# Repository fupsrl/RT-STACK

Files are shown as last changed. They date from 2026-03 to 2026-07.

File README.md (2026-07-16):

<p align="center">
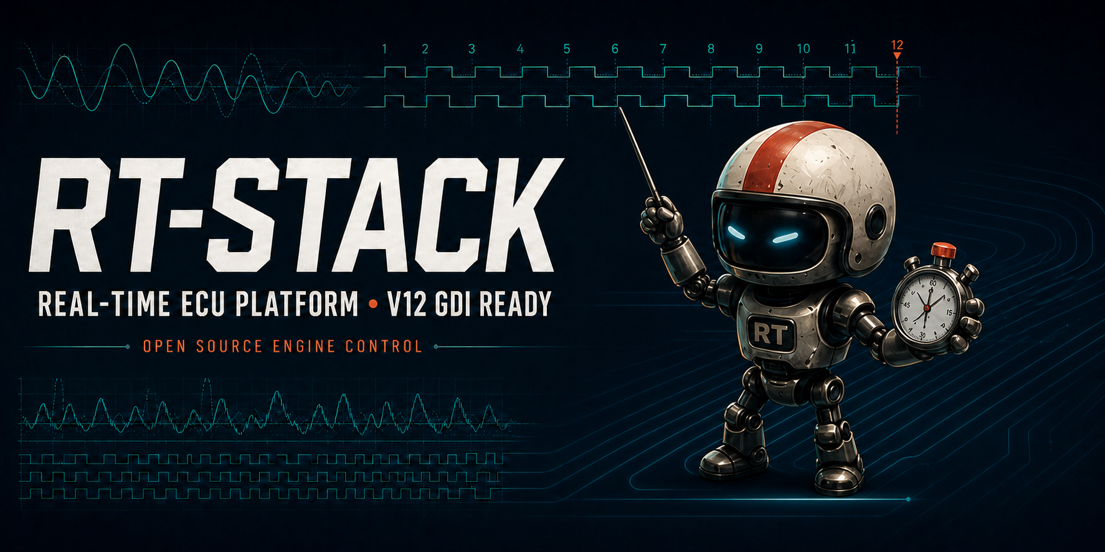
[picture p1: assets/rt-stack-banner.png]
RT-STACK — real-time ECU platform, V12 GDI ready
  
</p>

# RT-STACK

**RT-STACK is an open-source, real-time engine-control platform for experimental, motorsport, and bench-development applications.** It combines a deterministic STM32G4 real-time controller with the option to add a Raspberry Pi or another high-level computer for advanced control, data handling, and calibration workflows.

The hardware is deliberately ambitious—twelve injector channels, twelve ignition channels, trigger inputs, lambda interfaces, CAN, and a standard ECU connector—while the checked-in firmware is a transparent, configurable reference implementation. Start on the bench, understand every signal, then adapt the engine, trigger, and output configuration for your application.

> [!WARNING]
> RT-STACK is an engineering/development project. It is not certified, not road-legal, and is supplied without warranty. Do not connect coils, injectors, fuel pumps, or a running engine until you have independently validated the wiring, trigger decode, outputs, and failsafe behaviour on a safe bench setup.

## Why RT-STACK?

- **Real-time where it matters** — the STM32G474 handles time-critical trigger capture, injection and ignition scheduling.
- **Headroom where it helps** — a companion SBC can run high-level logic, graphical control models, logging, and calibration tooling without putting hard real-time output timing at risk.
- **Engine-agnostic by design** — the platform can be adapted for 2-stroke, 4-stroke, Wankel, Diesel, naturally aspirated, or forced-induction projects.
- **A serious hardware base** — the board is designed for high-channel-count PFI/GDI injection, inductive ignition, trigger sensing, lambda control, and general-purpose outputs.
- **Open calibration path** — the wider FUPSRL toolchain supports CAN/XCP workflows and A2L/HEX artefacts for tools such as ETAS INCA and Vector CANape. The current firmware also includes a 500 kbit/s classic-CAN status message and its DBC.

## Architecture

```text
Crank / cam / sensors
        │
        ▼
STM32G474 real-time layer ──► injector, ignition and I/O drivers
        │                         ▲
        ├── CAN telemetry          │ deterministic time-critical control
        ▼                         │
Optional SBC / high-level layer ──┘
  control logic · logging · calibration · user interface
```

The STM32 is the safety- and timing-critical controller. A companion computer is optional and should be treated as a supervisory layer, not as a replacement for deterministic output control.

## Hardware capabilities

| Area | Capability |
| --- | --- |
| Fuel | 12 injector drivers, intended for general-purpose GDI or PFI use; high-voltage DC/DC injector drive and current sensing |
| Ignition | 12 inductive-spark channels |
| Position sensing | 9 general-purpose trigger interfaces for crank, cam, turbo speed, or other timing inputs |
| Lambda | 2 × CJ125 lambda-controller interfaces |
| Outputs | 12 general-purpose outputs with selectable push/pull behaviour |
| Communications | FDCAN-capable MCU; the checked-in project configures classic CAN at 500 kbit/s and includes two UARTs |
| Processor | STM32G474VETx, with analogue comparators and DAC thresholds for injector-drive control |
| Integration | 186-pin standard ECU connector; designed to stack with a Raspberry Pi breakout board for high-level control |

Selected devices include the STM32G474VETx, ACS722 current sensing, CJ125 lambda interfaces, IR2101/TC4427 gate drivers, RGPR30BM40 ignition IGBTs, and IFX007TAUMA1 push/pull drivers. Consult the KiCad design and BOM before making any electrical decision; this README is an overview, not a wiring specification.

## Firmware: current scope

The firmware project lives in [`SW/RT_STACK_V2`](SW/RT_STACK_V2) and is an STM32CubeIDE / STM32CubeMX project. It provides a clear reference structure rather than a sealed, generic binary:

- **Trigger capture and decoding** — trigger edges are timestamped with the DWT cycle counter. The included decoder is configured for a 60-2 crank wheel, optional cam recognition, and 0–720° phase fusion.
- **Engine configuration** — cylinder count, firing order, ignition/injector channel mapping, dwell limit, boost time, and comparator thresholds are centralised in [`engine_config.h`](SW/RT_STACK_V2/Core/Inc/engine_config.h).
- **Trigger configuration** — crank-wheel and cam-pattern settings are centralised in [`trigger_decoder_config.h`](SW/RT_STACK_V2/Core/Inc/trigger_decoder_config.h).
- **Output scheduling** — [`spark.c`](SW/RT_STACK_V2/Core/Src/spark.c) and [`injection.c`](SW/RT_STACK_V2/Core/Src/injection.c) schedule the configured engine channels.
- **Telemetry** — `RT_Status` is sent as an 8-byte classic-CAN frame at identifier `0x100` every 10 ms; [`RT_STACK_V2.dbc`](SW/RT_STACK_V2/RT_STACK_V2.dbc) describes that message.

The committed engine calibration is an **inline-four example** (firing order `1-3-4-2`) and is not a V12 calibration. V12 readiness describes the available I/O architecture; you must supply a correctly validated configuration for every target engine.

## Quick start — safe development workflow

1. Clone the repository and open [`SW/RT_STACK_V2`](SW/RT_STACK_V2) in STM32CubeIDE. The `.ioc` file retains the CubeMX peripheral configuration.
2. Read `engine_config.h` and `trigger_decoder_config.h` before connecting any engine hardware. Configure only a bench-known target first.
3. Build the **Debug** configuration and flash through a correctly wired ST-LINK connection.
4. With injectors and coils disconnected, verify power rails, CAN traffic, trigger-edge polarity, decoded crank angle, RPM, and cam phase using instruments you trust.
5. Validate each output with suitable loads or test fixtures. Add engine actuation only after the whole chain has been checked.

For a guided explanation of the architecture, firmware configuration, CAN telemetry, calibration direction, and bench validation, read the [RT-STACK documentation](https://fupsrl.com/docs/rt-stack-documentation-v1/).

## Repository layout

| Path | Contents |
| --- | --- |
| [`HW`](HW) | KiCad hardware design files |
| [`FAB`](FAB) | Fabrication/manufacturing material |
| [`SW/RT_STACK_V2`](SW/RT_STACK_V2) | STM32CubeIDE firmware project, DBC, source, and CubeMX configuration |
| [`assets`](assets) | Repository artwork, including this README banner |

## Hardware preview

<p align="center">
  RT-STACK front
  RT-STACK rear
</p>

## Calibration and companion tools

RT-STACK is designed to sit within a broader open tooling workflow. The [CM-STACK Simulink Compiler](https://github.com/fupsrl/CM-STACK-Simulink-Compiler) creates deployable generic-Linux applications and calibration artefacts, while [INCAZ](https://github.com/fupsrl/INCAZ) is a lightweight measurement, calibration, and flash client. Treat each integration as a separately validated engineering step.

## Contributing and support

Issues and pull requests are welcome, especially reproducible trigger-decoder tests, documentation corrections, and validated engine configurations. Please include the RT-STACK revision, firmware commit, engine/trigger setup, power supply conditions, and the measurements or logs that demonstrate the behaviour.

## License

RT-STACK is licensed under [Creative Commons Attribution-NonCommercial 4.0 International](LICENSE.txt). Attribution is required and commercial use is not permitted.

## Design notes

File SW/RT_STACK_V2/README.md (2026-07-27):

# RT_STACK_V2 firmware

This firmware is organized around four intentionally separate concerns:

1. `trigger_capture_stm32.c` timestamps electrical edges.
2. `trigger_decoder.c` interprets user-defined wheel geometry.
3. `engine_control.c` gates the ignition/injection schedulers through a
   fail-safe engine state machine.
4. `dcdc_control.c` regulates VBUS, `dcdc_pwm_stm32.c` owns the
   hardware-synchronous two-phase TIM1 waveform, and
   `dcdc_platform_stm32.c` contains the board/ADC/interrupt integration.

`main.c` is now platform startup and sensor glue. Engine behavior is configured
in tables rather than embedded in the superloop.

## Start here

### 1. Configure the trigger wheels

Edit `Core/Inc/trigger_decoder_config.h`.

- Add one entry to `trigger_wheels[]` for every physical wheel.
- Set its TMG input channel, active edge, mechanical cycle, measured index-zero
  angle, direction, tolerances, filtering, confirmation count, and timeout.
- Choose either a conventional missing-tooth `N-M` wheel or an arbitrary cyclic
  `SHORT`/`LONG` interval pattern.
- Set `wheel_count`, `primary_wheel`, and optional `phase_wheel` in
  `trigger_default_config`.
- Set a measured crank/cam phase-alignment tolerance when a phase wheel is
  enabled.

The default is a crank-only 60-2 wheel on TMG1/PD10. The documented cam example
is deliberately disabled because its actual installed angle must be measured.
Sequential ignition and injection will not run without a configured phase
wheel.

The decoder itself accepts increasing or decreasing angle conventions and
general related wheel cycles. The present ignition/injection scheduler is
intentionally narrower: it enables actuators only for a +1 primary direction,
a 360-degree primary cycle, and a 720-degree engine cycle. Other combinations
remain usable for decoder development but fail actuator compatibility checks.

See [TRIGGER_DECODER.md](TRIGGER_DECODER.md) for pattern conventions, capture
pin capabilities, and integration details.

### 2. Configure the engine and actuators

Edit `Core/Inc/engine_config.h`.

- Set `ENGINE_CYLINDER_COUNT`.
- Give every cylinder an explicit compression TDC, ignition output, and injector
  output. Explicit TDCs support even-fire and odd-fire engines equally.
- Set per-cylinder ignition advance/dwell defaults and accepted limits.
- Set per-cylinder injection start, duration, boost time, and boost/hold DAC
  values.
- Select sequential or intentionally crank-only operation with
  `IGNITION_REQUIRES_PHASE_SYNC` and `INJECTION_REQUIRES_PHASE_SYNC`.

The engine gate derives its phase requirement from the currently enabled
commands. Enabling a sequential command without cam phase moves the controller
to `SYNCING`; disabling all sequential commands permits an intentionally
configured crank-only scheduler without requiring a reboot.

Physical PCB routing is separate in `Core/Inc/board_output_config.h`; it should
change only for a board revision.

Injection is disabled and calibration-locked by default. The fitted ACS722
sensor is bidirectional, so its nominal midscale is not a safe boost limit and
the example raw DAC codes must not be used with a load. Measure zero-current
code, polarity, codes/ampere, and the required boost/hold currents on every
pair; enter the resulting codes, then set
`INJECTION_CURRENT_CALIBRATION_VALID=1` and deliberately enable injection.
The six current comparators default to 10 mV hysteresis through
`BOARD_INJECTOR_COMPARATOR_HYSTERESIS`; validate that value against measured
noise and current ripple as part of the same calibration.

### 3. Deliberately arm outputs

`ENGINE_OUTPUTS_ARM_AT_BOOT` defaults to `0`. This keeps the firmware safe for
decoder and communications development. Setting it to `1` requests output
operation, but does not bypass configuration validation, synchronization, RPM
limits, event deadlines, or the fault latch.

The application can instead call:

```c
engine_control_request_outputs(true);
```

Only a fault-free `ENGINE_MODE_RUNNING` state can energize an output. Clear a
recoverable fault only after revoking output permission:

```c
engine_control_request_outputs(false);
engine_control_clear_faults();
```

### Stationary injector bench API

The periodic injector test is deliberately unavailable in production builds.
It requires both `INJECTION_CURRENT_CALIBRATION_VALID=1` and
`ENGINE_INJECTOR_TEST_API_ENABLED=1` in `Core/Inc/engine_config.h`. Enable it
only after the peak-and-hold current calibration has been measured on the
assembled board.

The API addresses the physical injector output number (`1..12`), not a
cylinder number. The selected output must appear exactly once in
`engine_cylinders[]`, because that cylinder entry supplies its calibrated
boost/hold profile and accepted pulse-width limits.

```c
engine_injector_test_config_t test = {
  .injector_output = 2U, /* physical INJ2 output */
  .period_ms = 100U,
  .pulse_width_us = 5000U
};

engine_injector_test_result_t result =
    engine_control_start_injector_test(&test);

/* Call engine_control_service() normally while the test is armed. */

engine_control_stop_injector_test();
```

`period_ms` is the start-to-start period and `pulse_width_us` is the injector
on-time. The first pulse occurs only after one complete period; late foreground
service skips missed periods and never emits a catch-up burst. Configured
minimum off-time, maximum duty cycle, mapped-cylinder duration limits, and the
normal 100 us hard-off deadline still apply.

The controller accepts the test only while the engine is stationary, normal
outputs are disarmed, no trigger records are pending, the trigger inputs have
been quiet for `ENGINE_INJECTOR_TEST_QUIET_TIME_MS` (also after startup or an
overcapture), and no fault is latched.
Only one injector may be tested at a time. While armed, the controller reports
`ENGINE_MODE_INJECTOR_TEST` and rejects normal output arming. Any trigger edge
immediately switches every injector off, cancels the test, and latches
`INJECTION_FAULT_DEBUG_INTERLOCK`; revoke output permission and clear faults
before attempting another test.

## Two-phase DCDC control

The boost converter uses two independent, active-high low-side phases:

- PC0/TIM1_CH1 drives Q31/L1 through the non-inverting TC4427;
- PE13/TIM1_CH3 drives Q32/L2 through the other TC4427 channel.

TIM1 counts up and down. CH1 runs PWM1 with `CCR1 = on_ticks`; CH3 runs PWM2
with `CCR3 = ARR - on_ticks`. The two pulses have equal duty and their centers
and corresponding steady-state edges are exactly one half-period apart. Phase
overlap above 50% is intentional for an interleaved boost converter; these are
not complementary half-bridge switches and timer deadtime is not applied.

All user calibration is in `Core/Inc/dcdc_config.h`. Before any output can be
enabled, that file requires explicit confirmation of feedback linearity,
hardware current-limit protection, and measured power-stage calibration. Then
enter the measured switching frequency, minimum on/off times, duty envelope,
VBUS target/trip/recovery limits, raw ADC watchdog threshold, soft-start rate,
and PID gains. The target and safety values are deliberately zero in the
repository because safe values cannot be inferred from unspecified inductor,
capacitor, thermal, and load ratings.

Runtime control is explicit:

```c
/* PWM stays off until several fresh, plausible VBUS samples are confirmed. */
dcdc_control_request_enable(true);

/* A higher target follows the configured soft-start ramp. */
dcdc_control_set_target_mv(measured_safe_target_mv);

/* Stop switching. This does not discharge the output capacitors. */
dcdc_control_request_enable(false);

/* After a fault: keep disabled, provide a fresh safe VBUS sample, then clear. */
dcdc_control_clear_faults();
```

The boolean APIs report synchronous request acceptance, not a guarantee that
the converter remains enabled. A watchdog or emergency interrupt can latch a
fault immediately afterward; read `dcdc_control_get_state()` for authoritative
state and fault bits.

The controller accepts at most one update per configured control period and
uses the real, deadline-bounded elapsed time for its soft-start, filtered
derivative-on-measurement, and back-calculation anti-windup calculations. It
never emits catch-up duty bursts. Compare values are
preloaded and written as a pair while update events are suppressed, so a timer
boundary cannot mix one old phase with one new phase. A zero-duty command
clears MOE/CEN/channel enables and returns both pins to GPIO-low; a later
nonzero command starts both timer channels as one hardware operation.

VBUS uses PC3/ADC1_IN9. The feedback network is physically:

```text
VBUS -- R145 25 kOhm --+-- VBUS_ADC / PC3
                       +-- R146 1 kOhm -- GND
                       +-- D53 LED ------ GND
                           anode   cathode
```

Without D53, `VADC = VBUS / 26`. D53 is not in series as a harmless indicator;
it is parallel to R146. Once `VADC` approaches the LED forward voltage, LED
current shunts the lower resistor and the transfer becomes nonlinear:

```text
(VBUS - VADC) / 25k = VADC / 1k + I_LED(VADC)
```

The approximate onset is `VBUS = 26 * Vf`: about 47 V for a 1.8 V red LED,
52 V for 2.0 V, 57 V for 2.2 V, or 78 V for a 3.0 V blue/white LED. D53 has no
specified part number, color, minimum-hot `Vf`, or datasheet, so no onset can be
relied on. As a simple 2.0 V clamp illustration, a real 60/80/100 V bus can be
reported near 52 V while LED current rises to roughly 0.32/1.12/1.92 mA. A real
LED has a sloped I-V curve rather than a hard clamp, but it remains strongly
temperature- and part-dependent. The PID can therefore integrate toward maximum
duty while real VBUS keeps rising, and the ADC analog watchdog is blinded if its
threshold is above the same apparent plateau.

D53 must be removed/DNP and the divider characterized before closed-loop use.
On the next PCB, put the indicator on its own rated resistor chain or buffered
driver. R145 is also a single unspecified 0402: with an approximately 2 V ADC
node it dissipates about 85 mW at 48 V, 135 mW at 60 V, and 243 mW at 80 V,
while sustaining roughly 46/58/78 V. Replace it with a voltage- and
power-derated series resistor chain, and add an independent precision
overvoltage comparator to TIM1 break or the power-stage enable.

There is also no phase-current sensing, cycle-by-cycle current limit, external
DCDC enable, or TIM1 break input on the current board. Firmware adds a raw ADC
analog-watchdog shutdown and a 1 ms off-only foreground deadline check, but
neither can protect against inductor saturation, a short, a failed MCU, or a
blocked interrupt. Hardware current limiting, a break/enable path, input
pull-downs, battery transient protection, and validated component ratings are
required before loaded operation. Stopping PWM leaves roughly millifarads of
VBUS capacitance charged; treat OFF as "not switching," not "safe voltage."

## Trigger capture: input capture versus EXTI

Input capture improves timestamp precision because the timer latches the edge
before interrupt latency. It does not remove the ISR or increase throughput by
itself; DMA would be required for that.

A full input-capture conversion is not possible on this PCB: the default crank
PD10 and PD11 have no direct capture channel, several alternatives consume a
shared 16-bit timer, and TIM1 channels conflict with existing outputs. The
implemented hybrid uses:

- free-running 32-bit TIM2 at the APB1 timer clock as the common timebase;
- TIM2_CH4 hardware capture for PA10/TMG5;
- short EXTI handlers that read `TIM2->CNT` for the remaining TMG pins;
- lock-free per-channel queues merged chronologically in the foreground.

Rising+falling (`TRIGGER_EDGE_BOTH`) is accepted only on PA10/TMG5. An EXTI
pending bit cannot retain two opposite edges or their order, so the platform
rejects BOTH-edge configurations on every EXTI-backed TMG input.

This also resolves the PA10/PD10 EXTI-line-10 collision. Queue overflow or TIM2
overcapture is never hidden: synchronization is invalidated and all actuators
are shut down.

## Ignition and injection behavior

Commands are explicit and validated:

```c
spark_command_t spark = { true, 20.0f, 3000U };
injection_command_t fuel = { true, 360.0f, 8000U };

spark_set_command(1U, &spark);
injection_set_command(1U, &fuel);
```

An active event keeps an immutable copy of its timing. Updating a command only
affects the next engine cycle. Shared peak-and-hold injector pairs have explicit
ownership; ambiguous simultaneous events fail closed instead of depending on
table order.

TIM2 compare channel 1 runs a 100 us safety service. It may end coil dwell,
BOOST, or injection, but it can never start an output. Main-loop stalls,
position loss, invalid numeric commands, excessive angle steps, output-pair
collisions, CPU faults, queue overflow, and capture overrun all lead toward OFF.

The independent hardware watchdog is also enabled after platform initialization.
It is refreshed only after a complete foreground control pass and resets the MCU
after roughly one second if that loop locks up. The timeout uses the imprecise
LSI clock and is deliberately not frozen by a debugger; it complements the
100 us actuator deadline service rather than replacing it.

Important hardware limitation: the current PCB has no independent global
driver-enable/break line. Timer IRQ deadlines protect against foreground stalls,
but no software can force GPIO low while the CPU is halted or physically
failed. The actuator/logic inputs also have no external fail-safe pull-downs,
so they are indeterminate during reset before firmware can configure the GPIOs.
Firmware now drives every IGN/BOOST/SEL/comparator-output and DCDC driver net
low directly from `Reset_Handler`, before clock/RAM/C-runtime initialization,
which shortens that window but cannot eliminate the reset interval itself.
Validate with protected dummy loads before connecting coils, injectors, or the
power stage; a future board must add pull-downs and a hardware
watchdog-controlled global driver enable.

PB8/BOOT0 also has no external pull-down. Firmware programs the option bytes to
ignore BOOT0 and boot from flash, but that code can run only after the application
has already booted once. Production boards must program those option bytes during
manufacturing or add a physical pull-down; firmware alone cannot guarantee the
first cold boot.

## Sensors and CAN

- PB2/ADC2_IN12 now supplies the external VBATT reading and uses a long sampling
  time suitable for a divider.
- ADC1 VREFINT is used to calculate VDDA for MCU temperature compensation.
- CAN frames are nonblocking and defined in `RT_STACK_V2.dbc`:
  - `0x100` backward-compatible angle/temperature/raw-voltage status;
  - `0x101` RPM, engine mode, sync/output flags, epoch, and VDDA;
  - `0x102` engine/trigger/actuator faults and loss counters.

### CAN hardware blocker

The present PCB connects MCU PA11 to TJA1051 `TXD` and PA12 to TJA1051 `RXD`,
but STM32G474 FDCAN1 requires PA11=`RX` and PA12=`TX`. Besides preventing CAN
operation, enabling the peripheral would make the PA12 output contend with the
transceiver `RXD` output. Firmware therefore leaves both pins passive and CAN
disabled by default. Swap the two logic-side nets (or use a corrected board),
then set `BOARD_FDCAN1_TRANSCEIVER_WIRING_FIXED` to `1` in
`Core/Inc/board_config.h`.

## CubeMX ownership and regeneration

`Core` is STM32CubeMX's application-code directory; it is not the CMSIS CPU
core. The ownership boundary inside it is important:

- `main.c`, `stm32g4xx_it.c`, `stm32g4xx_hal_msp.c`, and their matching headers
  are Cube-generated scaffolding. Custom code in them is limited to marked
  `USER CODE` blocks.
- Timer modes, pins, DMA and the HSE/PLL configuration are owned by
  `RT_STACK_V2.ioc`. The generated `SystemClock_Config()` and `MX_TIM1_Init()`
  bodies must not be hand-maintained.
- Files such as `engine_control.c`, `trigger_decoder.c`, `dcdc_control.c`, and
  `dcdc_platform_stm32.c` are user-owned modules and Cube leaves them intact.
- `main.c` contains only short initialization/service calls for those modules.
  The generated SysTick handler contains one off-only DCDC deadline hook. The
  fast ADC1 watchdog vector is implemented entirely in
  `dcdc_platform_stm32.c`, so it cannot be erased by regeneration.

ADC1_2 NVIC enable is deliberately owned by the DCDC platform module rather
than the `.ioc`: it is enabled only when all DCDC hardware/calibration gates
permit output, and its first action is the direct MOE shutdown. Do not also
enable the same vector in CubeMX without first changing the platform to use the
Cube-generated handler/HAL callback, or two vector definitions would conflict.

The checked configuration has been regenerated in an isolated directory with
STM32CubeMX and clean-built with STM32CubeIDE. Custom modules and protected hooks
survive; generated clock and TIM1 code are reproduced from the `.ioc`.

## Verification

Trigger host tests:

```text
gcc -std=c11 -Wall -Wextra -Werror -pedantic -ICore/Inc \
  Tests/trigger_decoder_test.c Core/Src/trigger_decoder.c \
  Core/Src/trigger_recorder.c -lm -o trigger_decoder_test
./trigger_decoder_test
```

Actuator host tests:

```text
gcc -std=c11 -Wall -Wextra -Werror -pedantic -DACTUATOR_HOST_TEST \
  -DINJECTION_CURRENT_CALIBRATION_VALID=1 \
  -DENGINE_INJECTOR_TEST_API_ENABLED=1 \
  -ICore/Inc -ICore/Src -ITests/actuators Tests/actuators/test_actuators.c \
  Core/Src/spark.c Core/Src/injection.c -lm -o test_actuators
./test_actuators
```

The CMake test project runs the trigger decoder, sequential actuators,
crank-only actuators, engine-control integration, and pure DCDC PWM/PID suites
with strict warnings. All suites are hardware-independent. The checked CubeIDE
Debug build also links all STM32 sources using the repository linker script.

Before loaded-engine use, perform hardware-in-the-loop sweeps for every wheel
pattern and RPM range, sensor disconnects, noisy/extra/missing edges, stopped
engine at every active-output phase, queue/overcapture injection, and measured
maximum coil/BOOST/injector pulse widths.

## Clock source

The confirmed 20 MHz HSE crystal is the PLL source: `20 MHz / 2 * 34 / 2 =
170 MHz`. Voltage scaling remains range-1 boost, flash latency remains four wait
states, and AHB/APB1/APB2 remain undivided, so TIM1 still receives 170 MHz.
Clock security is enabled after `SystemClock_Config()`. Loss of HSE enters NMI,
forces ignition, injection and DCDC outputs off, then resets the MCU. If USB or
another exact-48-MHz peripheral is added later, use HSI48/CRS rather than trying
to derive 48 MHz from the 340 MHz PLL VCO.

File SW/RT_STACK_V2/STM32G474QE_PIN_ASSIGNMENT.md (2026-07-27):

# STM32G474QE pin assignment for the RT-STACK redesign

Status: proposed LQFP128 board contract, checked against the STM32CubeMX 6.17 device database for `STM32G474Q(B-C-E)Tx`. It intentionally does not change the current STM32G474VET6 `.ioc`; the present firmware still targets the old LQFP100 board.

The machine-readable, package-pin-by-package-pin assignment is in [STM32G474QE_PIN_ASSIGNMENT.csv](STM32G474QE_PIN_ASSIGNMENT.csv). The 24 serialized outputs have their own contract in [STM32G474QE_SERIAL_OUTPUT_ASSIGNMENT.csv](STM32G474QE_SERIAL_OUTPUT_ASSIGNMENT.csv).

## Design assumptions

This assignment keeps all functions found in the current firmware and the draft `mcu.kicad_sch`:

- nine crank/cam/spare timing inputs;
- 12 ignition commands;
- six injector-pair select, BOOST, current-sense and comparator paths;
- 12 conditioned 12 V inputs and 12 protected 12 V outputs;
- two interleaved DCDC PWM outputs, VBUS feedback and a hardware-limit input;
- two CJ125 wideband-lambda interfaces with independent ADC and heater-control paths;
- three FDCAN buses, four serial links and two dedicated SPI buses;
- a 24-bit serialized low-speed control bank, including nine programmable trigger pull-ups;
- two status LEDs, HSE, SWD, reset and boot control.

It also preserves the existing external injector current-limit gates, so `COMP1_OUT` through `COMP6_OUT` still consume physical pins. Removing those six pads is possible only if the external gating circuit is redesigned around internal timer/HRTIM break paths.

## Serialized low-speed control and programmable pull-ups

The timing sheet already contains U62, an 8-bit `SN74LV8T595`-style part, although its outputs are currently unconnected. Nine trigger pull-ups alone exceed that capacity. Reuse U62 as the first stage and make the new chain **24 bits: U62 plus two additional 8-bit stages**. A single additional stage would provide only 16 bits and is too tight once safe output-enable, direct CJ125 chip selects, CJ125 reset and preservation of PA0/USB/BOOT0 are included.

SPI1 is dedicated to this output chain:

| Signal | MCU pin | Function |
|---|---:|---|
| `SERIAL_CTRL_SCK` | PG2 / pin 84 | SPI1_SCK, AF5 |
| `SERIAL_CTRL_MOSI` | PG4 / pin 86 | SPI1_MOSI, AF5 |
| `SERIAL_CTRL_LATCH` | PG5 / pin 103 | Storage-register clock |
| `SERIAL_CTRL_OE_N` | PF2 / pin 26 | Asynchronous bank disable, external pull-up |

Cascade each stage's serial output into the next stage and latch all 24 bits atomically:

| Bit | Logical output | Reset-safe value |
|---:|---|---:|
| 0 | `CRANK_PULLUP_EN` | 0 |
| 1 | `CAM1_PULLUP_EN` | 0 |
| 2 | `CAM2_PULLUP_EN` | 0 |
| 3 | `CAM3_PULLUP_EN` | 0 |
| 4 | `CAM4_PULLUP_EN` | 0 |
| 5 | `SPARE1_PULLUP_EN` | 0 |
| 6 | `SPARE2_PULLUP_EN` | 0 |
| 7 | `SPARE3_PULLUP_EN` | 0 |
| 8 | `SPARE4_PULLUP_EN` | 0 |
| 9 | `GPIO12V_OUT1` | 0 |
| 10 | `GPIO12V_OUT2` | 0 |
| 11 | `GPIO12V_OUT3` | 0 |
| 12 | `GPIO12V_OUT4` | 0 |
| 13 | `GPIO12V_OUT8` | 0 |
| 14 | `GPIO12V_OUT9` | 0 |
| 15 | `GPIO12V_OUT11` | 0 |
| 16 | `GPIO12V_OUT12` | 0 |
| 17 | `LED2` | 0 |
| 18 | `CJ125_RESET_RELEASE` | 0 |
| 19–23 | Reserved | 0 |

Only slow, non-timing protected outputs move to this bank. `IGNx`, injector select, BOOST, DCDC and both lambda-heater PWM signals remain direct MCU outputs. The serialized `GPIO12V_OUT` channels are not suitable for edge-scheduled injection/ignition or independent high-rate PWM.

The pull-up bits must control a high-side switch or analog switch that inserts each raw input's +5 V pull-up resistor. Do not connect a shift-register output directly to a trigger signal: driving a logic zero would clamp the sensor input rather than disconnect its pull-up. Keep the comparator-output-side +3.3 V pull-ups fixed so every MCU capture input always has a defined logic level.

`/OE` must not remain tied low as it is in the current draft. Give PF2 an external pull-up and arrange `/SRCLR` and the external load controls so reset means disabled. Firmware must hold PF2 high, shift the complete all-zero safe image, pulse `SERIAL_CTRL_LATCH`, and only then drive PF2 low. External pull-downs must keep every load off while the register outputs are high impedance; the level-shifted CJ125 reset must remain asserted. A watchdog or MCU reset must immediately return `/OE` high.

Maintain one 24-bit shadow word and update it under one owner. Every transaction transmits all 24 bits before one latch pulse, so unrelated outputs cannot glitch. Treat trigger electrical-mode changes as stopped-engine configuration: disable capture processing, update and latch the pull-up mask, clear pending/overcapture state, then reacquire synchronization.

Expose this as a named per-channel setting such as `trigger[i].pullup = DISABLED | ENABLED`; never expose serialized bit numbers to the user. Validate the requested electrical mode alongside polarity, capture edge and digital-filter settings before accepting a wheel configuration.

## The nine trigger inputs

The correct peripheral mode is **timer input capture**, not input compare. The G474 has only two 32-bit general-purpose timers, TIM2 and TIM5, with four capture channels each. Therefore eight 32-bit captures is the physical maximum; a ninth independent 32-bit capture does not exist on this MCU.

| Logical input | Package pin | Port | Capture channel | AF | Counter |
|---|---:|---|---|---:|---:|
| CRANK_TRG | 113 | PD3 | TIM2_CH1 | 2 | 32 bit |
| CAM1_TRG | 114 | PD4 | TIM2_CH2 | 2 | 32 bit |
| CAM2_TRG | 117 | PD7 | TIM2_CH3 | 2 | 32 bit |
| CAM3_TRG | 116 | PD6 | TIM2_CH4 | 2 | 32 bit |
| CAM4_TRG | 97 | PF6 | TIM5_CH1 | 6 | 32 bit |
| SPARE1_TRG | 15 | PF7 | TIM5_CH2 | 6 | 32 bit |
| SPARE2_TRG | 16 | PF8 | TIM5_CH3 | 6 | 32 bit |
| SPARE3_TRG | 17 | PF9 | TIM5_CH4 | 6 | 32 bit |
| SPARE4_TRG | 1 | PE2 | TIM3_CH1 | 2 | 16 bit + software epoch |

This mapping deliberately spends the two QUADSPI pin banks and some FMC alternatives. It avoids PA0–PA3, the fast ADC5 pins and almost all HRTIM pins. That is the right trade unless external parallel/QSPI memory is a firm requirement.

At a suggested 10 MHz common timer tick, TIM2/TIM5 wrap after about 429.5 s and TIM3 wraps every 6.5536 ms. Maintain a TIM3 overflow epoch and form a wider timestamp before passing an event to the decoder. The clock rate, filter and polarity belong in per-channel configuration; do not bake them into the ISR.

TIM2, TIM5 and TIM3 must share a timestamp domain. Configure the same timer-kernel clock and prescaler, synchronize their initial reset/start through the timer master/slave ITR network where the final CubeMX configuration permits it, and verify the measured counter offsets at startup. Do not compare raw CCR values from independently started counters.

### Is capture actually better than EXTI plus an ISR?

Yes. The current EXTI path timestamps an edge only after interrupt entry by reading `TIM2->CNT`, so interrupt latency and pre-emption become timestamp error. Input capture latches the counter in `CCR1..CCR4` at the hardware edge. ISR latency then affects only how quickly the sample is drained, not its time.

It also gives:

- per-channel edge polarity and digital filtering;
- an overcapture flag when software fails to drain a previous edge;
- DMA as an option for the highest-rate channels;
- a clean ISR that copies `{CCR, edge, status}` into a queue while decoding remains outside interrupt context.

The limitation is that each channel still has one CCR latch. A second edge before the first is consumed causes overcapture, so use DMA or a sufficiently short interrupt path for the crank input.

## Timed outputs

The remaining timer-rich pins are assigned to functions that benefit from deterministic edges:

| Function group | Pins/peripheral | Result |
|---|---|---|
| IGN1–4 | PF12–PF15 / TIM20_CH1–4 | Four hardware output-compare channels |
| IGN5–8 | PE9, PE11, PE13, PE14 / TIM1_CH1–4 | Four hardware output-compare channels |
| IGN9–10 | PE3, PE4 / TIM3_CH2–3 | Shares the 10 MHz time base with SPARE4 capture |
| IGN11 | PB15 / HRTIM1_CHD2 | HRTIM set/reset output |
| IGN12 | PA6 / TIM16_CH1 | Hardware output-compare channel |
| BOOST12–BOOST1112 | PA8, PA9, PA10, PB12, PB13, PB14 / HRTIM A1, A2, B1, C1, C2, D1 | Six independently controlled high-resolution outputs |
| DCDC phases | PC8, PC9 / HRTIM E1, E2 | One HRTIM timing unit, two interleaved outputs |
| Lambda heater 1 | PF10 / TIM15_CH2 | Independent hardware PWM, AF3 |
| Lambda heater 2 | PB7 / TIM4_CH2 | Independent hardware PWM, AF2 |

Every actuator command is active high. Add a physical pull-down at each gate/driver input and initialize timer output state and GPIO output-data registers before switching a pad to output or alternate-function mode.

The mixed timer instances should be hidden behind a table-driven channel descriptor. User-facing configuration should identify `IGN1`, `BOOST34`, and so on; it should never require the user to know that one channel is on TIM20 and another is on HRTIM D.

## DCDC implementation

Use PC8/HRTIM1_CHE1 and PC9/HRTIM1_CHE2. For period `T` and duty `D`:

- phase A set event: `0`; reset event: `D*T`;
- phase B set event: `T/2`; reset event: `(T/2 + D*T) mod T`.

Write all compare values through HRTIM preload registers and transfer them on the same period event. Trigger the VBUS ADC conversion from HRTIM at a repeatable quiet point in the switching cycle, feed that sample to the PID, clamp the requested duty and rate-limit it before the next preload transfer.

PD14/COMP7_INP is reserved for an independent DCDC overcurrent/overvoltage signal. Route COMP7 internally to HRTIM external event 5 or 10 for a cycle-by-cycle output reset. Use PB11/HRTIM1_FLT4 for the separately latched gate-driver or analog fault that requires an explicit clear. PB10 is a resistor-selectable second external fault option on HRTIM1_FLT3.

The DCDC must start disabled and stay disabled until clocks, ADC calibration, VBUS plausibility and fault inputs are valid. PID software is not a substitute for cycle-by-cycle hardware shutdown.

## Dual CJ125 lambda interfaces

Both CJ125s share SPI4 but retain direct, separately pulled-up chip selects:

| CJ125 signal | Channel 1 | Channel 2 | Notes |
|---|---|---|---|
| SPI clock | PE12 / SPI4_SCK | Shared | AF5 |
| SPI data to CJ125 | PE6 / SPI4_MOSI | Shared | AF5 |
| SPI data from CJ125 | PE5 / SPI4_MISO | Shared | AF5; only the selected device may drive it |
| `/SS` | PG0 | PG1 | Direct GPIO; high/inactive through reset |
| `UA` | PC0 / ADC1_IN6 | PA4 / ADC2_IN17 | Lambda/pump-current signal |
| `UR` | PE8 / ADC3_IN6 | PE10 / ADC4_IN14 | Ri/temperature signal |
| Heater PWM | PF10 / TIM15_CH2 | PB7 / TIM4_CH2 | Direct hardware PWM; never serialized |
| `/RST` | `SERIAL_Q18` | Shared | Active low through a proper 5 V-domain reset/level-shift stage |

ADC1/ADC2 can sample the two `UA` channels simultaneously, while ADC3/ADC4 can do the same for both `UR` channels. This keeps PA0 available for future fast analog work. Bosch specifies 16-bit SPI frames at up to 2 Mbaud. Keep the CJ125 bus on SPI4 and the output registers on SPI1; this avoids changing SPI mode or disturbing the serialized control image during lambda traffic.

CJ125 is a 5 V device. Use explicit unidirectional 3.3 V-to-5 V translation for SCK, MOSI, both `/SS` signals and reset, and a 5 V-to-3.3 V path for MISO. Pull both `/SS` inputs high on the CJ125 side. Do not assume that a nominally 5 V-tolerant STM32 input solves the output-high threshold in the opposite direction.

The existing `uego.kicad_sch` divides each `UA` and `UR` output with 600 ohm over 1 kohm. Its 0.625 ratio is appropriate for mapping approximately 5 V into the 3.3 V ADC range, but its roughly 1.6 kohm total resistance loads the CJ125 output by milliamps. Bosch specifies the `UA` output swing under a load below 10 microamps. Replace that network with a high-impedance divider followed by an ADC buffer, or buffer first and then attenuate; retain anti-alias filtering and ADC clamp protection. Route the scaled signals listed above, never raw 5 V-domain `UA`/`UR`.

Each heater needs a protected low-side power stage, hard gate-off bias and independent duty control. Connect CJ125 `DIAHG` to its heater gate and `DIAHD` to its drain through the Bosch application resistor so SPI diagnostics can detect open load and shorts. The LSU 4.9 specifies heater PWM at 100 Hz or above and about 7.5 W steady-state power. Heater control must include battery-voltage feed-forward, a condensation/dew-point delay, a controlled warm-up ramp, and closed-loop correction from `UR`; maximum duty must never be applied immediately to a cold sensor.

The existing CJ125 sheet is a useful starting point, not layout-ready. Its SCK and `/SS` symbol directions are wrong for ERC, the heater-driver connectivity needs review, and the library footprint is `SO24W` while Bosch's current public product page lists LQFP32. Freeze the exact CJ125 ordering code and validate its package/pinout before routing.

## Analog and injector current paths

| Pair | Comparator/ADC input | Physical comparator output | Internal threshold |
|---|---|---|---|
| INJ1/2 | PA1 / COMP1_INP / ADC1_IN2 | PF4 / COMP1_OUT | DAC1_CH1 |
| INJ3/4 | PA7 / COMP2_INP / ADC2_IN4 | PB9 / COMP2_OUT | DAC1_CH2 |
| INJ5/6 | PC1 / COMP3_INP / ADC1_IN7 | PC2 / COMP3_OUT | DAC3_CH1 |
| INJ7/8 | PE7 / COMP4_INP / ADC3_IN4 | PB1 / COMP4_OUT | DAC3_CH2 |
| INJ9/10 | PD12 / COMP5_INP / ADC3_IN9 | PC7 / COMP5_OUT | DAC4_CH1 |
| INJ11/12 | PD11 / COMP6_INP / ADC3_IN8 | PC6 / COMP6_OUT | DAC4_CH2 |

The DAC thresholds are internal signals; do not spend DAC output pads on them. Moving COMP4–6 inputs away from PB0/PB11/PB13 preserves more useful HRTIM and analog combinations.

VBUS remains on PC3/ADC1_IN9, VBATT on PB2/ADC2_IN12 and injector temperature on PC4/ADC2_IN5. The new board must remove the LEDs currently connected across the VBUS and VBATT divider lower resistors. Those LEDs clamp and linearize neither measurement; they make both ADC readings voltage- and temperature-dependent. `LED1` remains a direct output on PD5; `LED2` moves to serialized output bit 17. Both require their own series resistors.

## Communications and debug

- FDCAN1: PD0 RX, PD1 TX.
- FDCAN2: PB5 RX, PB6 TX.
- FDCAN3: PB3 RX, PB4 TX.
- UART4: PC10 TX, PC11 RX.
- UART5: PC12 TX, PD2 RX.
- USART1: PE0 TX, PE1 RX.
- USART2: PA2 TX, PA3 RX.
- Dedicated output-control SPI1: PG2 SCK and PG4 MOSI, with PG5 as the 24-bit latch clock and PF2 as active-low output enable. PG3 remains assigned to `GPIO12VIN_7`; this write-only chain needs no MISO.
- Dedicated CJ125 SPI4: PE12 SCK, PE5 MISO and PE6 MOSI, with direct chip selects on PG0 and PG1. Name these nets `CJ125_SPI_*`; do not retain the misleading old `SPI3_*` names.

On every CAN transceiver, MCU TX goes to transceiver TXD pin 1, while transceiver RXD pin 4 goes to MCU RX. This corrects the direction error in the current CAN wiring.

Using PB3/PB4 for the third CAN bus means SWO and full JTAG are unavailable; SWD remains on PA13/PA14. If only two CAN buses are required, leave PB3/PB4 free and restore SWO.

The 20 MHz HSE crystal belongs on PF0/OSC_IN and PF1/OSC_OUT. PE0/PE1 are ordinary GPIO/USART pins and must not be connected to that crystal. Route PG10/NRST, PA13/SWDIO, PA14/SWCLK, 3.3 V sense and ground to the debug connector.

## Pins deliberately preserved

| Pin | Reason |
|---|---|
| PA0 | Fast ADC1/2, comparator and OPAMP-capable analog expansion |
| PA11/PA12 | The unique USB DM/DP pair |
| PB8/BOOT0 | Controlled boot strap plus HRTIM external-event capability |
| PA13/PA14 | SWD |
| PF0/PF1 | Confirmed HSE |
| PG10 | Reset |

PC14/PC15 are used as slow general inputs, so this assignment does not retain an LSE crystal. If RTC/LSE is required, move at least two slow `GPIO12VIN` signals to an external input register or expander.

## Board-level constraints before layout

1. Connect every VDD/VSS pair. Pins 43 and 44 are both VREF+ and both must be connected and decoupled; pin 45 is VDDA and pin 42 is VSSA.
2. Keep the 20 MHz crystal and its load network at PF0/PF1, with short symmetric traces and no connector stubs.
3. Put defined external pull-downs on IGN, BOOST, injector-select, DCDC and protected-output control inputs.
4. Route CRANK first, then CAM inputs, away from HRTIM/DCDC switching nodes. The MCU-side traces begin after the existing comparator and 3.3 V pull-up.
5. Add a real hardware DCDC fault path. Keep it independent of the PID and normal interrupt system.
6. Do not assume an analog-enabled pin is 5 V tolerant. Scale and clamp every external analog signal to the VDDA/VREF range.
7. Use an output-register family whose input thresholds are guaranteed at a 3.3 V MCU drive level and whose temperature/qualification match the product. Do not substitute a 5 V `74HC595` whose VIH is not guaranteed by a 3.3 V output.
8. Keep the eight serialized protected outputs explicitly classified as slow/non-safety-critical. If they need PWM, immediate fault reaction or independent availability, replace this chain with a qualified smart high-side/low-side SPI driver with diagnostics.
9. Validate both CJ125 5 V logic translation and the high-impedance `UA`/`UR` analog front ends before layout. Keep these traces away from DCDC and ignition edges.
10. The currently listed `STM32G474QET6` order code is industrial grade, not an automotive-qualified MCU. Confirm the required ambient/junction range and qualification before freezing an engine-bay production BOM.

## CubeMX and regeneration

The current `RT_STACK_V2.ioc` still describes the STM32G474VET6/LQFP100 production prototype. Re-targeting that file in place would make the existing board unbuildable and would mix two hardware variants.

Create a separate `RT_STACK_G474QE.ioc` only after this pin contract is accepted. Generated startup, linker and HAL initialization files should then be produced from that QE `.ioc`; application modules and the board/channel descriptor remain outside generated code. No hand edits should be required in generated IRQ, MSP or `main.c` sections except inside CubeMX `USER CODE` blocks.

## Primary references

- [STM32G474QE product page](https://www.st.com/en/microcontrollers-microprocessors/stm32g474qe.html)
- [STM32G474xB/C/E datasheet, DS12288](https://www.st.com/resource/en/datasheet/stm32g474qe.pdf)
- [STM32G4 reference manual, RM0440](https://www.st.com/resource/en/reference_manual/rm0440-stm32g4-series-advanced-armbased-32bit-mcus-stmicroelectronics.pdf)
- [Bosch CJ125 product page](https://www.bosch-semiconductors.com/products/automotive-ics/ice-powertrain/cj125/)
- [Bosch CJ125 product information](https://www.bosch-semiconductors.com/media/automotive_systems_ics/pdf_1/ic_engine_management/cj125_product_info_2019-02.pdf)
- [Bosch LSU 4.9 datasheet](https://www.bosch-motorsport.com/content/downloads/Raceparts/Resources/pdf/Data%20Sheet_69034379_Lambda_Sensor_LSU_4.9.pdf)

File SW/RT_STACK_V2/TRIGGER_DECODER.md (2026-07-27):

# Trigger decoder and capture backend

The trigger subsystem is split in two deliberately independent parts:

1. A **capture backend** records a physical channel, edge polarity, per-channel
   sequence number, and timestamp.
2. `trigger_decoder.c` interprets those events using the wheel table in
   `Core/Inc/trigger_decoder_config.h`.

Consequently wheel configuration does not depend on whether a timestamp came
from EXTI, timer input capture, DMA, or a host test.

## Input capture decision for this board

The STM32G474VE alternate-function table gives the following options:

| TMG net | MCU pin | Direct timer input-capture option |
|---|---|---|
| TMG_OUT1 | PD10 | none |
| TMG_OUT2 | PD12 | TIM4_CH1 (AF2) |
| TMG_OUT3 | PC9 | TIM3_CH4 (AF2), TIM8_CH4 (AF4) |
| TMG_OUT4 | PD14 | TIM4_CH3 (AF2) |
| TMG_OUT5 | PA10 | TIM1_CH3 (AF6), TIM2_CH4 (AF10) |
| TMG_OUT6 | PD11 | none (TIM5_ETR is available, but is not a CCR capture channel) |
| TMG_OUT7 | PD13 | TIM4_CH2 (AF2) |
| TMG_OUT8 | PD15 | TIM4_CH4 (AF2) |
| TMG_OUT9 | PA8 | TIM1_CH1 (AF6) |

Source: STM32G474xB/xC/xE datasheet, Table 13, alternate functions:
<https://www.st.com/resource/en/datasheet/stm32g474ve.pdf>.

Input capture is better **where a suitable channel exists**: the edge latches
the counter in hardware, so ISR latency does not become timestamp jitter, and
DMA/overcapture detection can be used. It is not a good whole-board replacement
here because:

- the default crank is TMG_OUT1/PD10, which has no capture channel;
- TMG_OUT6/PD11 also has no direct capture channel;
- TIM4 would be shared by four inputs and is only 16-bit;
- PA8/TMG_OUT9 and PA10/TMG_OUT5 overlap TIM1 channels already configured on
  PC0 and PE13 in this project;
- PD10/TMG_OUT1 and PA10/TMG_OUT5 both use EXTI line 10, so they cannot both be
  routed through EXTI at the same time.

The practical backend for this PCB is therefore hybrid:

- run free-running 32-bit TIM2 as the common timestamp clock;
- capture PA10/TMG_OUT5 in TIM2_CH4 (this also resolves the EXTI10 collision);
- for the remaining channels, read `TIM2->CNT` in the EXTI handler;
- put both kinds of timestamp into the same `trigger_recorder_t` queues.

TIM2 is owned exclusively by this backend and the actuator deadline service;
do not assign it to another CubeMX peripheral or application feature.

This gives every event the same clock domain. A future PCB should route the
primary crank input to a 32-bit timer channel if hardware capture/DMA is wanted
for the signal where it matters most.

EXTI is adequate at ordinary engine edge rates when its interrupt remains
short and highest priority. The recorder prevents foreground polling from
losing already-serviced edges. It cannot recover two physical edges that
coalesce into one EXTI pending bit while interrupts are blocked; that remains
an acquisition-backend limitation. For this reason the STM32 backend rejects
`TRIGGER_EDGE_BOTH` on EXTI-backed channels; BOTH is supported only on
PA10/TMG_OUT5 hardware capture. Use a single edge on all other TMG inputs.

## Integration API

Allocate one recorder, decoder, and output:

```c
static trigger_recorder_t trigger_recorder;
static trigger_decoder_t trigger_decoder;
static trigger_output_t trigger_output;
```

Initialize them after the common timestamp timer has been configured, but
before capture interrupts are enabled:

```c
trigger_recorder_init(&trigger_recorder);

trigger_config_error_t error = trigger_decoder_context_init(
    &trigger_decoder,
    trigger_decoder_default_config(),
    trigger_timestamp_hz);

if (error != TRIGGER_CONFIG_OK) {
    /* Keep actuators disabled and report
       trigger_decoder_config_error_string(error). */
}
```

The acquisition handler supplies the timestamp; the recorder never reads a
timer itself:

```c
(void)trigger_recorder_record_isr(&trigger_recorder,
                                  tmg_channel,
                                  TRIGGER_EDGE_RISING,
                                  captured_tim2_timestamp);
```

Drain all queued events before asking for the current state. Read `now` only
after draining, which guarantees it cannot predate the latest processed edge:

```c
trigger_event_t event;
while (trigger_recorder_pop_oldest(&trigger_recorder, &event)) {
    trigger_decoder_process_event(&trigger_decoder, &event);
}

uint32_t now = TIM2->CNT;
trigger_decoder_poll(&trigger_decoder, now, &trigger_output);
```

If timer `CCxOF`, a DMA overwrite, or another backend loss is detected, report
it immediately:

```c
trigger_decoder_note_event_loss(&trigger_decoder, tmg_channel, lost_count);
```

The per-channel sequence field independently catches recorder queue gaps at the
next event. Do not silently continue after an overcapture: position is no
longer knowable.

## User wheel configuration

Edit only `Core/Inc/trigger_decoder_config.h` for normal engine adaptation.

- Add/remove entries in `trigger_wheels[]` and set `wheel_count`.
- Select any physical TMG channel and rising/falling polarity per wheel. BOTH
  edges are available only on PA10/TMG_OUT5 with this board backend.
- Use `TRIGGER_WHEEL_MISSING_TOOTH` for N-M geometry.
- Use `TRIGGER_WHEEL_INTERVAL_PATTERN` for a cyclic array such as
  `{SHORT, SHORT, LONG, LONG}`.
- Set the exact angle at pattern index zero, direction, interval tolerance,
  filtering, confirmation count, glitch rejection, and stop timeout per wheel.
- Select the primary speed wheel and optional 720-degree phase wheel in
  `trigger_default_config`.
- Set `phase_alignment_tolerance_deg` to the maximum measured crank/cam angle
  error. It must be below half a primary revolution so the engine turn remains
  uniquely identifiable; use a much tighter measured value in practice.

Pattern rotations must be unique. For example `{S,L,S,L}` is rejected because
rotating it by two entries gives the same sequence; no decoder could know which
of those two positions was observed.

The default enables only the existing 60-2 crank definition. The example cam
is disabled because its real mechanical angle must be measured on the engine.

## Host verification

From `RT_STACK_V2`:

```text
gcc -std=c11 -Wall -Wextra -Werror -pedantic -ICore/Inc \
    Tests/trigger_decoder_test.c Core/Src/trigger_decoder.c \
    Core/Src/trigger_recorder.c -lm -o trigger_decoder_test
./trigger_decoder_test
```

The tests cover configuration rejection, 12-2 acquisition, exact reference
tooth counting, speed/angle interpolation, missing events, timeouts, arbitrary
LONG/SHORT acquisition, crank/cam 720-degree fusion, 32-bit timestamp wrap,
nonzero index/wrap continuity, phase acquisition during an interpolated wrap,
queue ordering, and queue overflow.

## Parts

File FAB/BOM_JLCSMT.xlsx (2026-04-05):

Comment | Designator | Footprint | JLCPCB Part #（optional）
1k | R164,R165,R148,R162,R144,R109,R125,R151,R146,R163,R155,R154,R112,R128,R158,R48,R21,R47,R23,R24,R44,R43,R45,R20,R19,R46,R22 | R_0402_1005Metric | C106235
100k | R139,R118,R133,R122,R135,R131,R114,R116,R140,R123 | R_0402_1005Metric | C481918
10 | R73,R71,R72,R67,R86,R81,R90,R83,R70,R79,R84,R82,R78,R68,R87,R80,R76,R69,R88,R77,R85,R89,R75,R74 | R_0402_1005Metric | C137925
60 | R168 | R_0402_1005Metric | C137954
6.8k | R115,R132 | R_0402_1005Metric | C137847
R0 | R13,R7,R2,R14,R1,R8 | R_0402_1005Metric | C106231
15 | R129,R110 | R_0402_1005Metric | C25083
301R | R117,R134 | R_0402_1005Metric | C477711
100 | R113,R130 | R_0402_1005Metric | C106232
5k | R143,R141,R142 | R_0402_1005Metric | C477765
4.7k | R121,R138 | R_0402_1005Metric | C105871
200 | R167,R147,R166 | R_0402_1005Metric | C114764
470k | R136,R119 | R_0402_1005Metric | C137976
600 | R127,R124,R108,R111 | R_0402_1005Metric | C5120110
61.9R | R137,R120 | R_0402_1005Metric | C137953
31.6K | R107,R126 | R_0402_1005Metric | C276265
25k | R145 | R_0402_1005Metric | C138027
0.51k | R30,R27,R25,R50,R53,R29,R49,R51,R52,R28,R54,R26 | R_0402_1005Metric | C276273
10k | R58,R32,R62,R59,R39,R65,R64,R56,R38,R61,R66,R37,R34,R40,R63,R31,R57,R33,R41,R42,R55,R60,R36,R35 | R_0402_1005Metric | C60489
10 | R102,R100,R18,R15,R9,R11,R16,R3,R10,R5,R17,R12,R6,R4 | R_0603_1608Metric | C109317
5.1 | R177,R175,R105,R173,R176,R174,R106,R104 | R_0603_1608Metric | C5759169
56k | R95,R99,R92,R103,R101,R97,R94,R98,R96 | R_0805_2012Metric | C137509
2K | R91,R93 | R_1206_3216Metric | C133543
100nF | C103,C64,C115,C22,C116,C11,C30,C2,C61,C73,C55,C21,C70,C5,C3,C12,C108,C109,C107,C20,C23,C1,C67,C19,C111,C13,C10,C58,C14,C4,C28,C117,C29,C42,C39,C53,C37,C41,C40,C38,C52,C49,C54,C50,C51,C101,C94,C99,C96,C97,C95,C98,C100,C124 | C_0402_1005Metric | C60474
1uF | C7,C104,C105,C15,C112,C113,C25,C6,C24,C16 | C_0402_1005Metric | C7500380
220nF | C63,C60,C66,C69,C68,C57,C65,C59,C72,C56,C62,C71 | C_0402_1005Metric | C162178
10nF | C27,C18,C9,C8,C26,C17 | C_0402_1005Metric | C60133
2.2nF | C102,C110 | C_0402_1005Metric | C106861
47p | C123,C122 | C_0402_1005Metric | C60137
15pF | C93,C92 | C_0402_1005Metric | C33149
1nF | C114,C106,C45,C44,C31,C35,C33,C43,C34,C47,C46,C48,C36,C32 | C_0402_1005Metric | C113780
470p | C74,C75 | C_0603_1608Metric | C107092
330p | C77,C76,C78 | C_0603_1608Metric | C62784
0.22uF | C79,C80 | C_0805_2012Metric | C513710
10uF | C118,C121,C120,C119 | CP_Elec_5x4.5 | C2164947
LED | D53,D55,D54,D52,D51,D56 | LED_0402_1005Metric | C22355736
1N4148WS | D17,D18,D10,D1,D9,D2 | D_SOD-323 | C60580
SN74AHC1G08DCKR | U4,U15,U17,U18,U9,U5,U6,U16,U12,U3,U10,U11 | SOT-353_SC-70-5 | C122838
ADCMP354 | U47,U52,U50,U46,U51,U48,U49,U53,U54 | Analog_KS-4 | C141911
SN74AHC1G02DCKR | U8,U7,U2,U14,U13,U1 | SOT-353_SC-70-5 | C7464
STM32G474VETx | U41 | LQFP-100_14x14mm_P0.5mm | C431632
Crystal_GND24 | Y1 | Crystal_SMD_2016-4Pin_2.0x1.6mm | C7294671

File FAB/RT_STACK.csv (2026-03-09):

Id | Riferimento | Impronta | Quantità | Valore | Produttore
1 | IC12,IC11,IC10,IC9,IC8,IC7,IC6,IC5,IC4,IC3,IC2,IC1 | PG-TO263-7-1 | 12 | IFX007TAUMA1
2 | U8,U7,U2,U14,U13,U1 | SOT-353_SC-70-5 | 6 | SN74AHC1G02DCKR
3 | R164,R165,R148,R162,R144,R109,R125,R151,R146,R163,R155,R154,R112,R128,R158,R48,R21,R47,R23,R24,R44,R43,R45,R20,R19,R46,R22 | R_0402_1005Metric | 27 | 1k
4 | C103,C64,C115,C22,C116,C11,C30,C2,C61,C73,C55,C21,C70,C5,C3,C12,C108,C109,C107,C20,C23,C1,C67,C19,C111,C13,C10,C58,C14,C4,C28,C117,C29,C42,C39,C53,C37,C41,C40,C38,C52,C49,C54,C50,C51 | C_0402_1005Metric | 45 | 100nF
5 | R73,R71,R72,R67,R86,R81,R90,R83,R70,R79,R84,R82,R78,R68,R87,R80,R76,R69,R88,R77,R85,R89,R75,R74 | R_0402_1005Metric | 24 | 10
6 | U47,U52,U50,U46,U51,U48,U49,U53,U54 | Analog_KS-4 | 9 | ADCMP354
7 | D7,D36,D39,D46,D35,D15,D27,D34,D25,D38,D3,D48,D19,D31,D20,D23,D28,D13,D24,D44,D45,D40,D14,D12,D16,D30,D5,D43,D47,D32,D26,D22,D6,D21,D4,D8,D37,D29,D41,D11,D33,D42 | D_SMB | 42 | SK520B
8 | U4,U15,U17,U18,U9,U5,U6,U16,U12,U3,U10,U11 | SOT-353_SC-70-5 | 12 | SN74AHC1G08DCKR
9 | R139,R118,R133,R122,R135,R131,R114,R116,R140,R123 | R_0402_1005Metric | 10 | 100k
10 | L1,L2 | L_Vishay_IHLP-6767 | 2 | 10uH
11 | U40,U39,U36,U37,U38,U33,U23,U35,U34,U28 | SOIC-8_3.9x4.9mm_P1.27mm | 10 | TC4427xOA
12 | R168 | R_0402_1005Metric | 1 | 60
13 | J6,J4,J7,J3 | PinSocket_2x10_P2.54mm_Vertical | 4 | Conn_02x10_Odd_Even
14 | R115,R132 | R_0402_1005Metric | 2 | 6.8k
15 | D53,D55,D54,D52,D51,D56 | LED_0402_1005Metric | 6 | LED
16 | U24,U30,U19,U25,U20,U29 | SOIC-8_3.9x4.9mm_P1.27mm | 6 | IR2101
17 | C101,C94,C99,C96,C97,C95,C98,C100 | C_0402_1005Metric | 8 | 100nf
18 | R13,R7,R2,R14,R1,R8 | R_0402_1005Metric | 6 | R0
19 | R177,R175,R105,R173,R176,R174,R106,R104 | R_0603_1608Metric | 8 | 5.1
20 | R129,R110 | R_0402_1005Metric | 2 | 15
21 | C7,C104,C105,C15,C112,C113,C25,C6,C24,C16 | C_0402_1005Metric | 10 | 1uF
22 | C63,C60,C66,C69,C68,C57,C65,C59,C72,C56,C62,C71 | C_0402_1005Metric | 12 | 220nF
23 | R149,R150,R161,R152,R156,R160,R153,R157,R159 | R_Axial_DIN0204_L3.6mm_D1.6mm_P1.90mm_Vertical | 9 | 1k
24 | C85,C84,C83,C81,C82,C86,C90,C87,C88,C91,C89 | CP_Radial_D12.5mm_P5.00mm | 11 | 330uF
25 | J12,J11 | PinSocket_2x03_P2.54mm_Vertical_SMD | 2 | Conn_02x03_Odd_Even
26 | R18,R15,R9,R11,R16,R3,R10,R5,R17,R12,R6,R4 | R_0402_1005Metric | 12 | R10
27 | R117,R134 | R_0402_1005Metric | 2 | 301R
28 | C74,C75 | C_0603_1608Metric | 2 | 470p
29 | R113,R130 | R_0402_1005Metric | 2 | 100
30 | C27,C18,C9,C8,C26,C17 | C_0402_1005Metric | 6 | 10nF
31 | R95,R99,R92,R103,R101,R97,R94,R98,R96 | R_0805_2012Metric | 9 | 56k
32 | R143,R141,R142 | R_0402_1005Metric | 3 | 5k
33 | R91,R93 | R_1206_3216Metric | 2 | 2K
34 | C118,C121,C120,C119 | CP_Elec_5x4.5 | 4 | 10uF
35 | D17,D18,D10,D1,D9,D2 | D_SOD-323 | 6 | 1N4148WS
36 | C77,C76,C78 | C_0603_1608Metric | 3 | 330p
37 | R121,R138 | R_0402_1005Metric | 2 | 4.7k
38 | C79,C80 | C_0805_2012Metric | 2 | 0.22uF
39 | R167,R147,R166 | R_0402_1005Metric | 3 | 200
40 | C124 | C_0402_1005Metric | 1 | 100n
41 | C102,C110 | C_0402_1005Metric | 2 | 2.2nF
42 | Q35,Q33 | Q_SOT-23 | 2 | SS8550
43 | R136,R119 | R_0402_1005Metric | 2 | 470k
44 | C123,C122 | C_0402_1005Metric | 2 | 47p
45 | JP4 | SolderJumper-2_P1.3mm_Open_RoundedPad1.0x1.5mm | 1 | Jumper_2_Open
46 | R127,R124,R108,R111 | R_0402_1005Metric | 4 | 600
47 | R137,R120 | R_0402_1005Metric | 2 | 61.9R
48 | U22,U26,U31,U27,U21,U32 | SOIC-8_3.9x4.9mm_P1.27mm | 6 | ACS722xLCTR-20AB
49 | U43,U42 | SO24W | 2 | CJ125
50 | R107,R126 | R_0402_1005Metric | 2 | 31.6K
51 | J2 | PinSocket_2x18_P2.54mm_Vertical_SMD | 1 | Conn_02x18_Odd_Even
52 | C93,C92 | C_0402_1005Metric | 2 | 15pF
53 | R145 | R_0402_1005Metric | 1 | 25k
54 | J10 | LD09S13A4GX00LF | 1 | LD09S13A4GX00LF
55 | C114,C106,C45,C44,C31,C35,C33,C43,C34,C47,C46,C48,C36,C32 | C_0402_1005Metric | 14 | 1nF
56 | U41 | LQFP-100_14x14mm_P0.5mm | 1 | STM32G474VETx
57 | J1 | CONN_5601380001-SD_MOL | 1 | 5601381861
58 | R102,R100 | R_0603_1608Metric | 2 | 10
59 | J5 | PinSocket_2x20_P2.54mm_Vertical | 1 | Conn_02x20_Odd_Even
60 | U55 | SOIC-8_3.9x4.9mm_P1.27mm | 1 | TJA1051T-3
61 | J8 | IDC-Header_2x07_P2.54mm_Vertical | 1 | Conn_02x07_Odd_Even
62 | Y1 | Crystal_SMD_2016-4Pin_2.0x1.6mm | 1 | Crystal_GND24
63 | J9 | PinSocket_2x15_P2.54mm_Vertical | 1 | Conn_02x15_Odd_Even
64 | Q17,Q12,Q7,Q1,Q15,Q2,Q18,Q4,Q16,Q10,Q9,Q11,Q3,Q14,Q13,Q6,Q8,Q5 | TO-252-2 | 18 | SUD80460E
65 | Q31,Q32 | TO-252-2 | 2 | BUK9230-100B
66 | Q27,Q19,Q28,Q22,Q25,Q20,Q21,Q29,Q30,Q26,Q23,Q24 | TO-252-2 | 12 | RGPR30BM40
67 | Q36,Q34 | TO-252-2 | 2 | STD30NF06LT4
68 | R30,R27,R25,R50,R53,R29,R49,R51,R52,R28,R54,R26 | R_0402_1005Metric | 12 | 0.51k
69 | D50,D49 | TO-263-2 | 2 | STTH802G-TR
70 | R58,R32,R62,R59,R39,R65,R64,R56,R38,R61,R66,R37,R34,R40,R63,R31,R57,R33,R41,R42,R55,R60,R36,R35 | R_0402_1005Metric | 24 | 10k
71 | U45 | TO-263-3_TabPin2 | 1 | LM1084-3.3
72 | U44 | TO-263-3_TabPin2 | 1 | LM1084-5.0

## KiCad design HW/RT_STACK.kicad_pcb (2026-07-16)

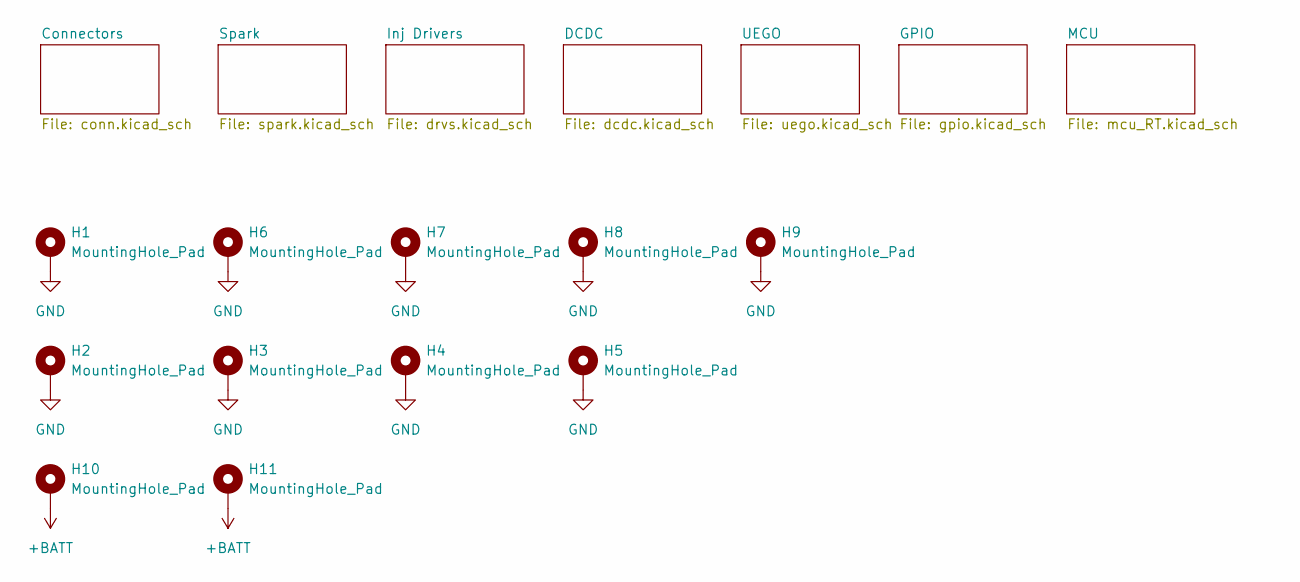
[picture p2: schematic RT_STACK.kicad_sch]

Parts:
H1, H6, H7, H8, H9, H10, H11: MountingHole_Pad; MountingHole_2.2mm_M2_DIN965_Pad_TopBottom
H2, H3, H4, H5: MountingHole_Pad; MountingHole_3.2mm_M3_DIN965_Pad_TopBottom

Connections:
+BATT: H10.1, H11.1; also elsewhere on the board
GND: H1.1, H2.1, H3.1, H4.1, H5.1, H6.1, H7.1, H8.1, H9.1; also elsewhere on the board

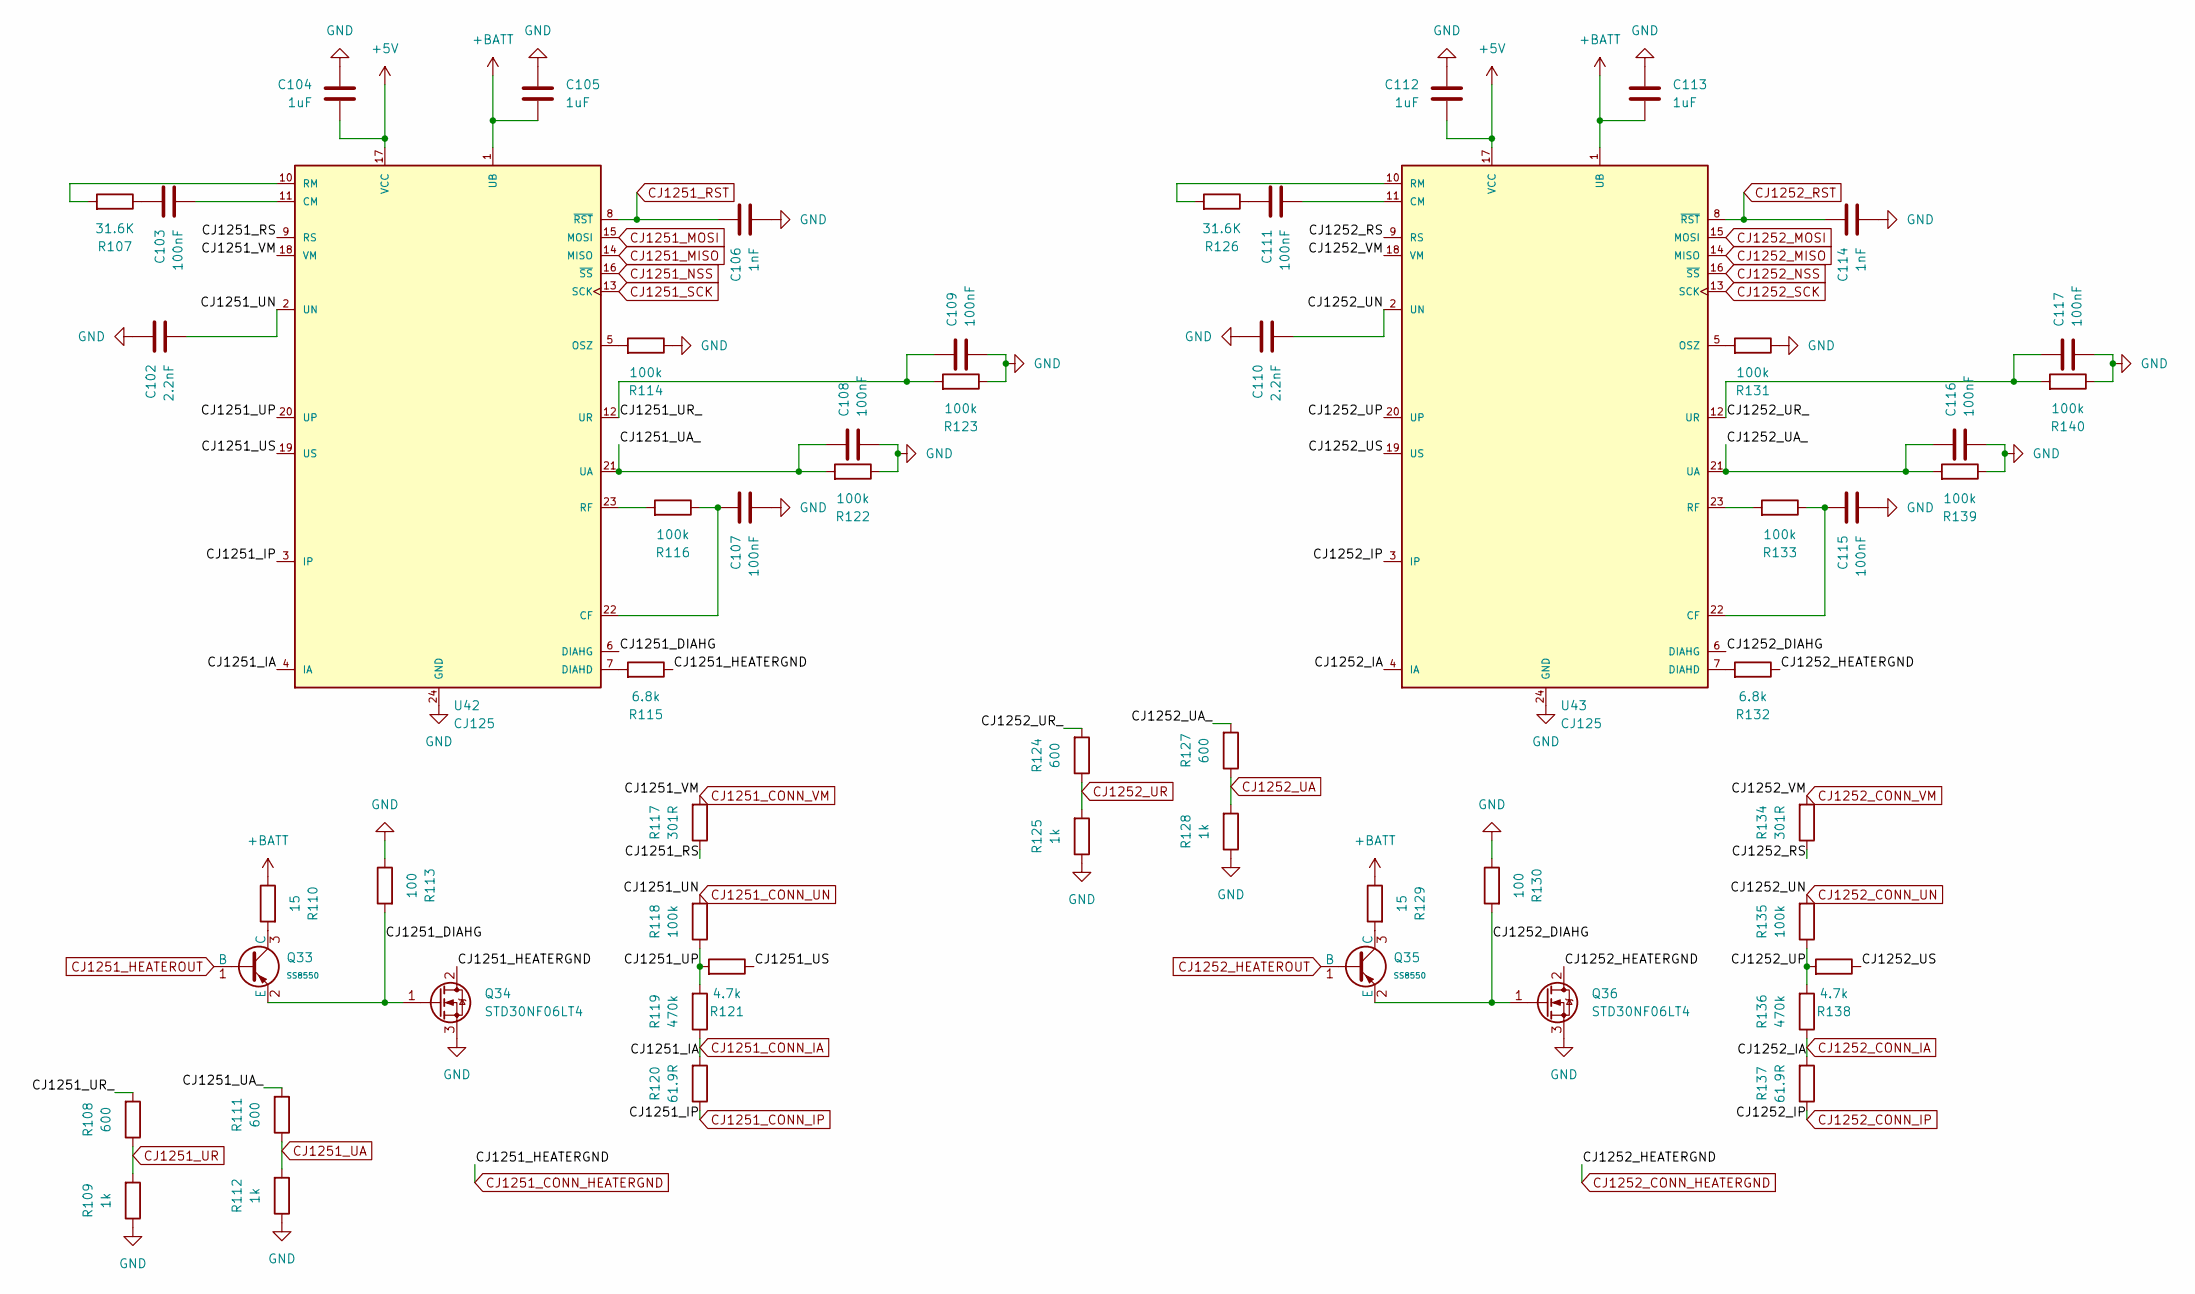
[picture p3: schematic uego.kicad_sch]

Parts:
C102, C110: 2.2nF; C_0402_1005Metric
C103, C107, C108, C109, C111, C115, C116, C117: 100nF; C_0402_1005Metric
C104, C105, C112, C113: 1uF; C_0402_1005Metric
C106, C114: 1nF; C_0402_1005Metric
Q33, Q35: SS8550; Q_SOT-23; Part SS8550; LCSC C7420371
Q34, Q36: STD30NF06LT4; TO-252-2
R107, R126: 31.6K; R_0402_1005Metric
R108, R111, R124, R127: 600; R_0402_1005Metric
R109, R112, R125, R128: 1k; R_0402_1005Metric
R110, R129: 15; R_0402_1005Metric
R113, R130: 100; R_0402_1005Metric
R114, R116, R118, R122, R123, R131, R133, R135, R139, R140: 100k; R_0402_1005Metric
R115, R132: 6.8k; R_0402_1005Metric
R117, R134: 301R; R_0402_1005Metric
R119, R136: 470k; R_0402_1005Metric
R120, R137: 61.9R; R_0402_1005Metric
R121, R138: 4.7k; R_0402_1005Metric
U42, U43: CJ125; SO24W

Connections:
+5V: C104.2, C112.2, U42.17 (VCC), U43.17 (VCC); also elsewhere on the board
+BATT: C105.2, C113.2, R110.1, R129.1, U42.1 (UB), U43.1 (UB); also elsewhere on the board
/UEGO/CJ1251_DIAHG: Q33.2 (E), Q34.1 (G), R113.2, U42.6 (DIAHG)
/UEGO/CJ1251_RS: R117.1, U42.9 (RS)
/UEGO/CJ1251_UA_: C108.1, R111.2, R122.2, U42.21 (UA)
/UEGO/CJ1251_UP: R118.1, R119.2, R121.2, U42.20 (UP)
/UEGO/CJ1251_UR_: C109.1, R108.2, R123.2, U42.12 (UR)
/UEGO/CJ1251_US: R121.1, U42.19 (US)
/UEGO/CJ1252_DIAHG: Q35.2 (E), Q36.1 (G), R130.2, U43.6 (DIAHG)
/UEGO/CJ1252_RS: R134.1, U43.9 (RS)
/UEGO/CJ1252_UA_: C116.1, R127.2, R139.2, U43.21 (UA)
/UEGO/CJ1252_UP: R135.1, R136.2, R138.2, U43.20 (UP)
/UEGO/CJ1252_UR_: C117.1, R124.2, R140.2, U43.12 (UR)
/UEGO/CJ1252_US: R138.1, U43.19 (US)
CJ1251_CONN_HEATERGND: Q34.2 (D), R115.1; also elsewhere on the board
CJ1251_CONN_IA: R119.1, R120.2, U42.4 (IA); also elsewhere on the board
CJ1251_CONN_IP: R120.1, U42.3 (IP); also elsewhere on the board
CJ1251_CONN_UN: C102.2, R118.2, U42.2 (UN); also elsewhere on the board
CJ1251_CONN_VM: R117.2, U42.18 (VM); also elsewhere on the board
CJ1251_HEATEROUT: Q33.1 (B); also elsewhere on the board
CJ1251_MISO: U42.14 (MISO); also elsewhere on the board
CJ1251_MOSI: U42.15 (MOSI); also elsewhere on the board
CJ1251_NSS: U42.16 (~SS); also elsewhere on the board
CJ1251_RST: C106.1, U42.8 (~RST)
CJ1251_SCK: U42.13 (SCK); also elsewhere on the board
CJ1251_UA: R111.1, R112.2; also elsewhere on the board
CJ1251_UR: R108.1, R109.2; also elsewhere on the board
CJ1252_CONN_HEATERGND: Q36.2 (D), R132.1; also elsewhere on the board
CJ1252_CONN_IA: R136.1, R137.2, U43.4 (IA); also elsewhere on the board
CJ1252_CONN_IP: R137.1, U43.3 (IP); also elsewhere on the board
CJ1252_CONN_UN: C110.2, R135.2, U43.2 (UN); also elsewhere on the board
CJ1252_CONN_VM: R134.2, U43.18 (VM); also elsewhere on the board
CJ1252_HEATEROUT: Q35.1 (B); also elsewhere on the board
CJ1252_MISO: U43.14 (MISO); also elsewhere on the board
CJ1252_MOSI: U43.15 (MOSI); also elsewhere on the board
CJ1252_NSS: U43.16 (~SS); also elsewhere on the board
CJ1252_RST: C114.1, U43.8 (~RST)
CJ1252_SCK: U43.13 (SCK); also elsewhere on the board
CJ1252_UA: R127.1, R128.2; also elsewhere on the board
CJ1252_UR: R124.1, R125.2; also elsewhere on the board
GND: C102.1, C104.1, C105.1, C106.2, C107.2, C108.2, C109.2, C110.1, C112.1, C113.1, C114.2, C115.2, C116.2, C117.2, Q34.3 (S), Q36.3 (S), R109.1, R112.1, R113.1, R114.1, R122.1, R123.1, R125.1, R128.1, R130.1, R131.1, R139.1, R140.1, U42.24 (GND), U43.24 (GND); also elsewhere on the board
unnamed: C103.1, R107.1
unnamed: C111.1, R126.1
unnamed: Q33.3 (C), R110.2
unnamed: Q35.3 (C), R129.2
unnamed: C107.1, R116.1, U42.22 (CF)
unnamed: C103.2, U42.11 (CM)
unnamed: R115.2, U42.7 (DIAHD)
unnamed: R114.2, U42.5 (OSZ)
unnamed: R116.2, U42.23 (RF)
unnamed: R107.2, U42.10 (RM)
unnamed: C115.1, R133.1, U43.22 (CF)
unnamed: C111.2, U43.11 (CM)
unnamed: R132.2, U43.7 (DIAHD)
unnamed: R131.2, U43.5 (OSZ)
unnamed: R133.2, U43.23 (RF)
unnamed: R126.2, U43.10 (RM)

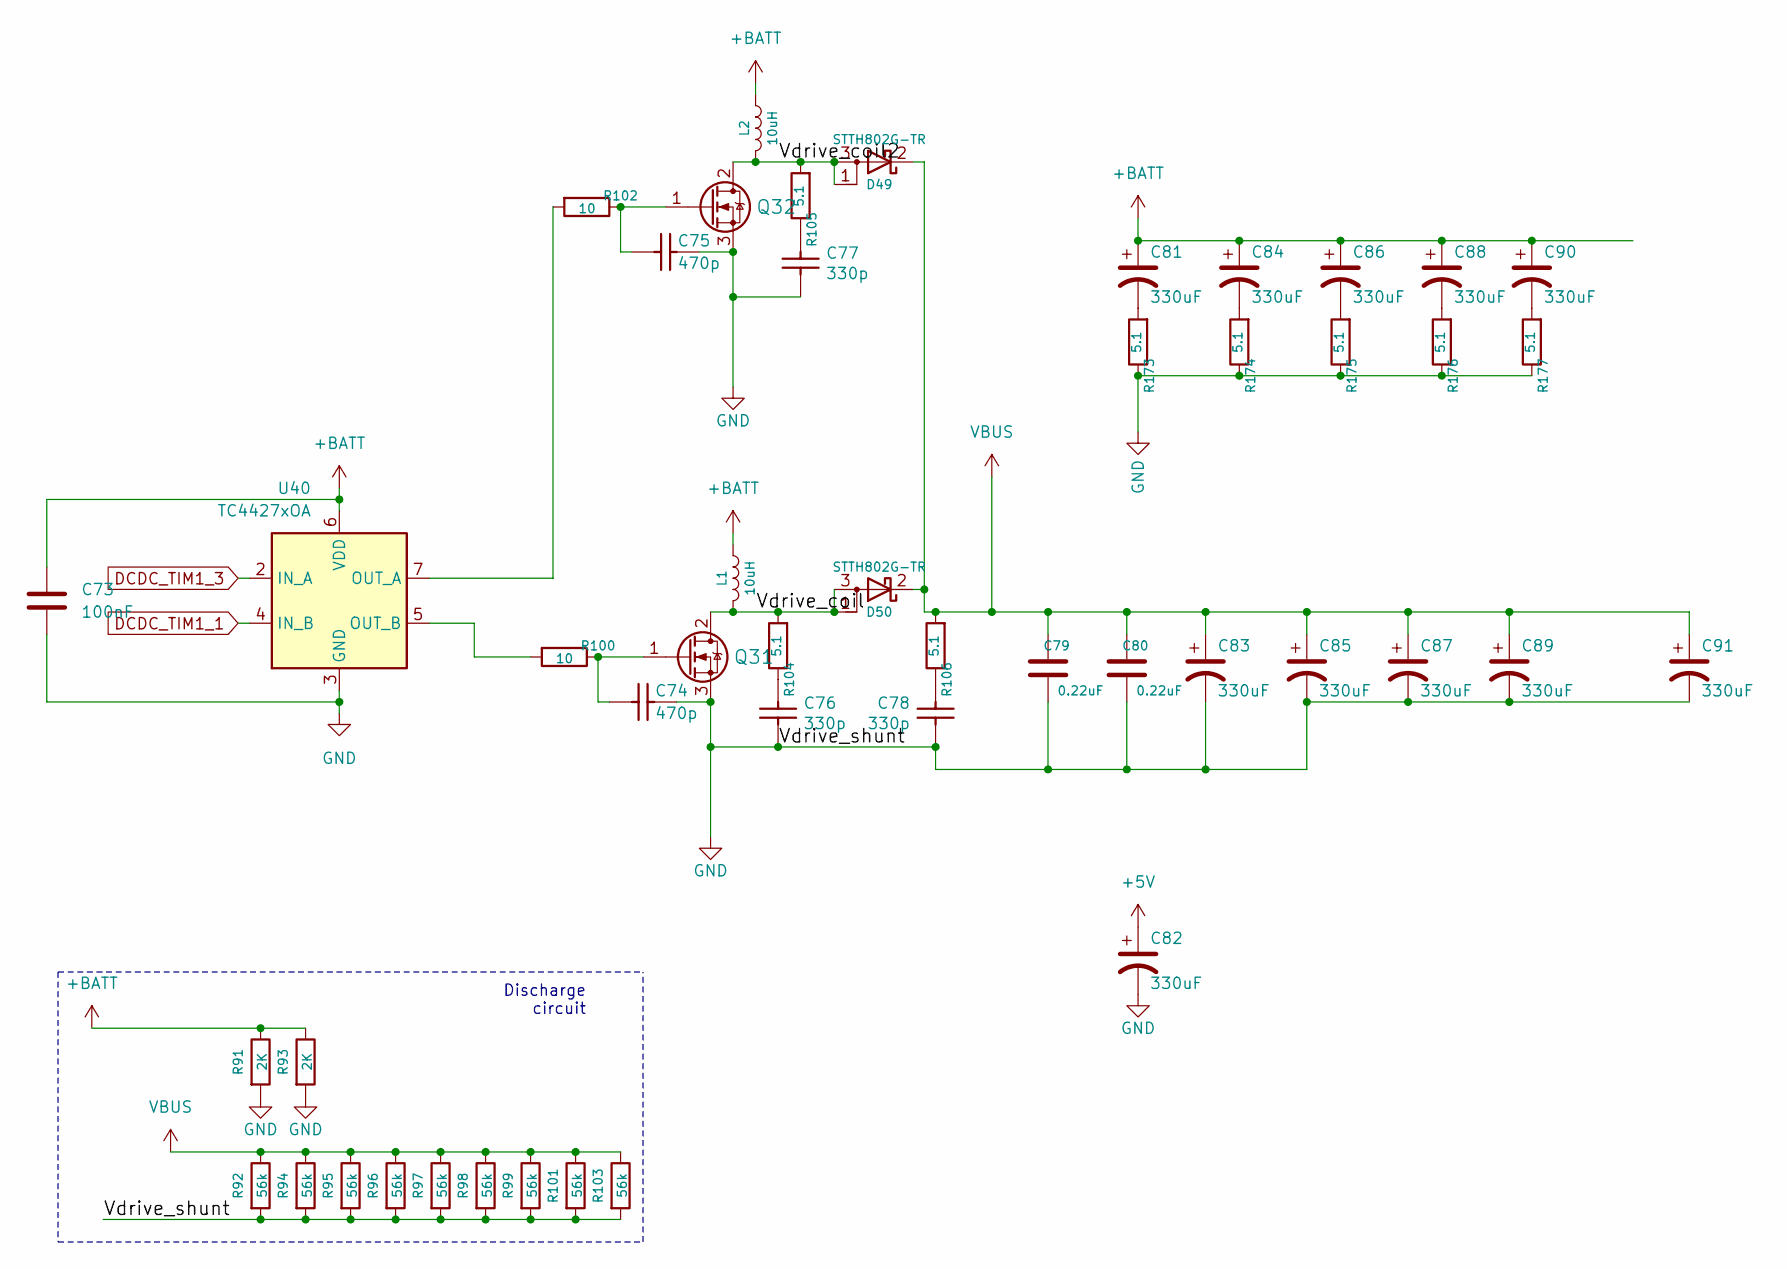
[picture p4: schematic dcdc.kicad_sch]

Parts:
C73: 100nF; C_0402_1005Metric; JLC C77020
C74, C75: 470p; C_0603_1608Metric; LCSC C326973
C76, C77, C78: 330p; C_0603_1608Metric; LCSC C576850
C79, C80: 0.22uF; C_0805_2012Metric; LCSC C513710
C81, C82, C83, C84, C85, C86, C87, C88, C89, C90, C91: 330uF; CP_Radial_D12.5mm_P5.00mm
D49, D50: STTH802G-TR; TO-263-2; LCSC C181034
L1, L2: 10uH; L_Vishay_IHLP-6767; LCSC C237980
Q31, Q32: BUK9230-100B; TO-252-2; LCSC C89735
R91, R93: 2K; R_1206_3216Metric; LCSC C17944
R92, R94, R95, R96, R97, R98, R99, R101, R103: 56k; R_0805_2012Metric; LCSC C17756
R100, R102: 10; R_0603_1608Metric; LCSC C60485
R104, R105, R106, R173, R174, R175, R176, R177: 5.1; R_0603_1608Metric; LCSC C25197
U40: TC4427xOA; SOIC-8_3.9x4.9mm_P1.27mm; JLC C640788

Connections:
+5V: C82.1; also elsewhere on the board
+BATT: C73.1, C81.1, C84.1, C86.1, C88.1, C90.1, L1.1, L2.1, R91.1, R93.1, U40.6 (VDD); also elsewhere on the board
/DCDC/Vdrive_coil: D50.1 (A), D50.3 (A), L1.2, Q31.2 (D), R104.2
/DCDC/Vdrive_coil2: D49.1 (A), D49.3 (A), L2.2, Q32.2 (D), R105.2
DCDC_TIM1_1: U40.4 (IN_B); also elsewhere on the board
DCDC_TIM1_3: U40.2 (IN_A); also elsewhere on the board
GND: C73.2, C74.1, C75.1, C76.1, C77.1, C78.1, C79.2, C80.2, C82.2, C83.2, C85.2, C87.2, C89.2, C91.2, Q31.3 (S), Q32.3 (S), R91.2, R92.2, R93.2, R94.2, R95.2, R96.2, R97.2, R98.2, R99.2, R101.2, R103.2, R173.1, R174.1, R175.1, R176.1, R177.1, U40.3 (GND); also elsewhere on the board
unnamed: C76.2, R104.1
unnamed: C77.2, R105.1
unnamed: C78.2, R106.1
unnamed: C81.2, R173.2
unnamed: C84.2, R174.2
unnamed: C86.2, R175.2
unnamed: C88.2, R176.2
unnamed: C90.2, R177.2
unnamed: C74.2, Q31.1 (G), R100.1
unnamed: C75.2, Q32.1 (G), R102.1
unnamed: R102.2, U40.7 (OUT_A)
unnamed: R100.2, U40.5 (OUT_B)
VBUS: C79.1, C80.1, C83.1, C85.1, C87.1, C89.1, C91.1, D49.2 (K), D50.2 (K), R92.1, R94.1, R95.1, R96.1, R97.1, R98.1, R99.1, R101.1, R103.1, R106.2; also elsewhere on the board

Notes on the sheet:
Discharge circuit

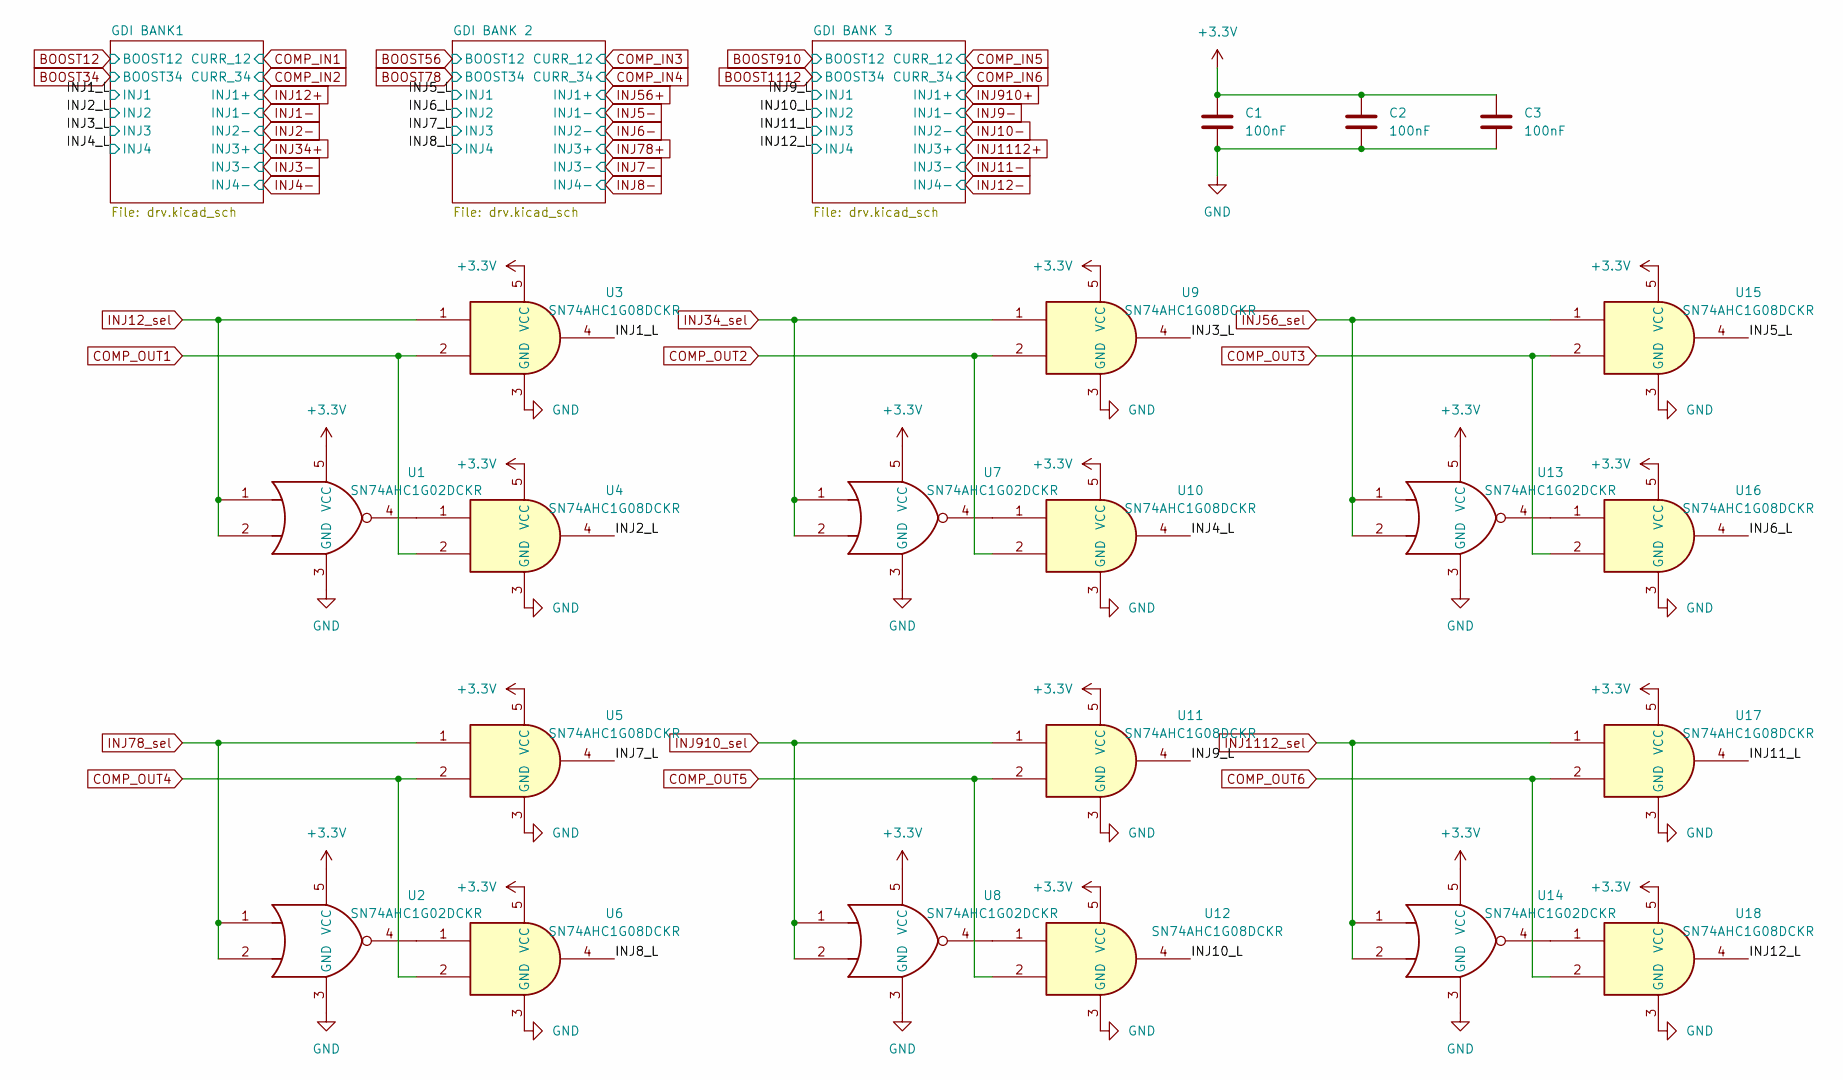
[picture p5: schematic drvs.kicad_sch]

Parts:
C1, C2, C3: 100nF; C_0402_1005Metric
U1, U2, U7, U8, U13, U14: SN74AHC1G02DCKR; SOT-353_SC-70-5; JLC C7464
U3, U4, U5, U6, U9, U10, U11, U12, U15, U16, U17, U18: SN74AHC1G08DCKR; SOT-353_SC-70-5; JLC C122838

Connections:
+3.3V: C1.1, C2.1, C3.1, U1.5 (VCC), U2.5 (VCC), U3.5 (VCC), U4.5 (VCC), U5.5 (VCC), U6.5 (VCC), U7.5 (VCC), U8.5 (VCC), U9.5 (VCC), U10.5 (VCC), U11.5 (VCC), U12.5 (VCC), U13.5 (VCC), U14.5 (VCC), U15.5 (VCC), U16.5 (VCC), U17.5 (VCC), U18.5 (VCC); also elsewhere on the board
/Inj Drivers/INJ1_L: U3.4; also elsewhere on the board
/Inj Drivers/INJ2_L: U4.4; also elsewhere on the board
/Inj Drivers/INJ3_L: U9.4; also elsewhere on the board
/Inj Drivers/INJ4_L: U10.4; also elsewhere on the board
/Inj Drivers/INJ5_L: U15.4; also elsewhere on the board
/Inj Drivers/INJ6_L: U16.4; also elsewhere on the board
/Inj Drivers/INJ7_L: U5.4; also elsewhere on the board
/Inj Drivers/INJ8_L: U6.4; also elsewhere on the board
/Inj Drivers/INJ9_L: U11.4; also elsewhere on the board
/Inj Drivers/INJ10_L: U12.4; also elsewhere on the board
/Inj Drivers/INJ11_L: U17.4; also elsewhere on the board
/Inj Drivers/INJ12_L: U18.4; also elsewhere on the board
COMP_OUT1: U3.2, U4.2; also elsewhere on the board
COMP_OUT2: U9.2, U10.2; also elsewhere on the board
COMP_OUT3: U15.2, U16.2; also elsewhere on the board
COMP_OUT4: U5.2, U6.2; also elsewhere on the board
COMP_OUT5: U11.2, U12.2; also elsewhere on the board
COMP_OUT6: U17.2, U18.2; also elsewhere on the board
GND: C1.2, C2.2, C3.2, U1.3 (GND), U2.3 (GND), U3.3 (GND), U4.3 (GND), U5.3 (GND), U6.3 (GND), U7.3 (GND), U8.3 (GND), U9.3 (GND), U10.3 (GND), U11.3 (GND), U12.3 (GND), U13.3 (GND), U14.3 (GND), U15.3 (GND), U16.3 (GND), U17.3 (GND), U18.3 (GND); also elsewhere on the board
INJ12_sel: U1.1, U1.2, U3.1; also elsewhere on the board
INJ34_sel: U7.1, U7.2, U9.1; also elsewhere on the board
INJ56_sel: U13.1, U13.2, U15.1; also elsewhere on the board
INJ78_sel: U2.1, U2.2, U5.1; also elsewhere on the board
INJ910_sel: U8.1, U8.2, U11.1; also elsewhere on the board
INJ1112_sel: U14.1, U14.2, U17.1; also elsewhere on the board
unnamed: U1.4, U4.1
unnamed: U2.4, U6.1
unnamed: U7.4, U10.1
unnamed: U8.4, U12.1
unnamed: U13.4, U16.1
unnamed: U14.4, U18.1

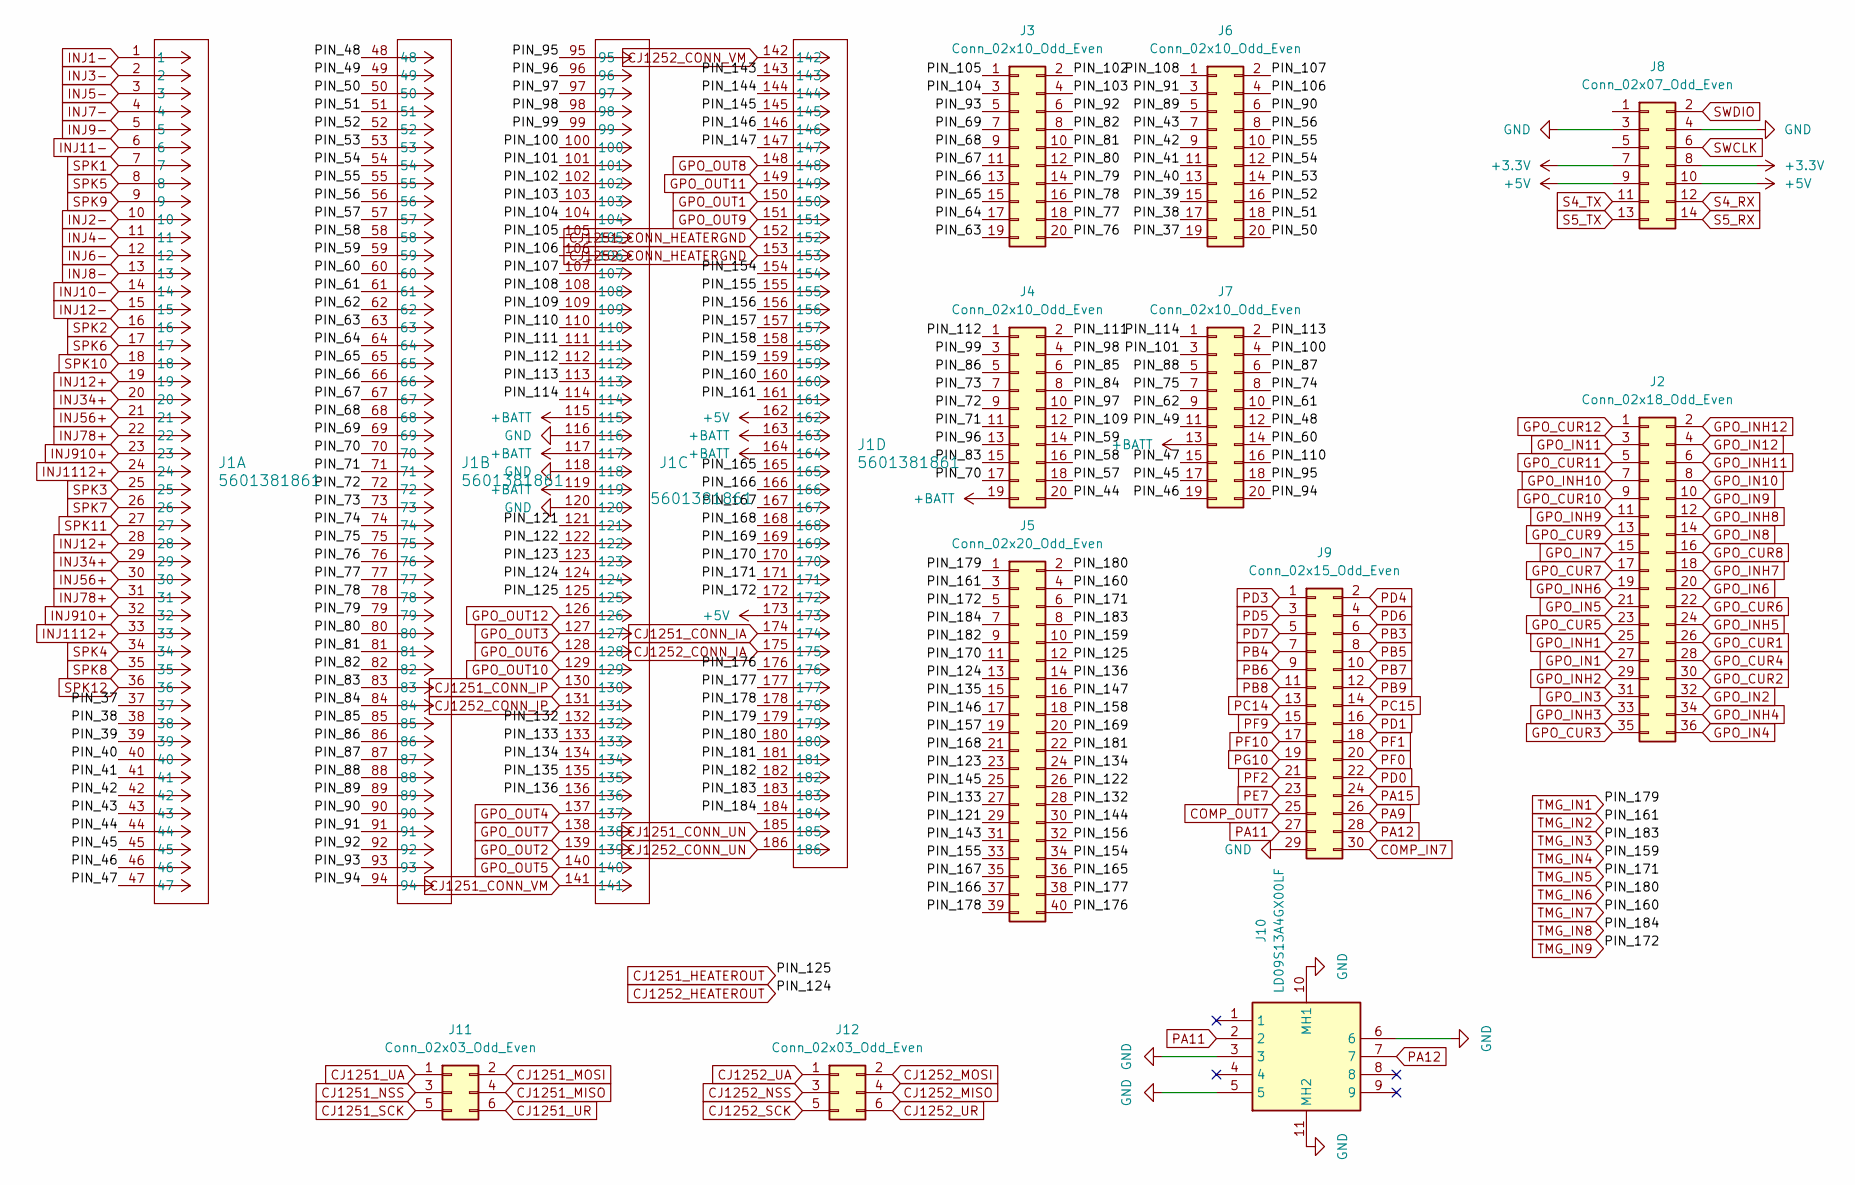
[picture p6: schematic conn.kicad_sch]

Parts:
J1: 5601381861; CONN_5601380001-SD_MOL
J2: Conn_02x18_Odd_Even; PinSocket_2x18_P2.54mm_Vertical_SMD
J3, J4, J6, J7: Conn_02x10_Odd_Even; PinSocket_2x10_P2.54mm_Vertical
J5: Conn_02x20_Odd_Even; PinSocket_2x20_P2.54mm_Vertical
J8: Conn_02x07_Odd_Even; IDC-Header_2x07_P2.54mm_Vertical
J9: Conn_02x15_Odd_Even; PinSocket_2x15_P2.54mm_Vertical
J10: LD09S13A4GX00LF; Manufacturer_Part_Number LD09S13A4GX00LF
J11, J12: Conn_02x03_Odd_Even; PinSocket_2x03_P2.54mm_Vertical_SMD

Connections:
+3.3V: J8.7, J8.8; also elsewhere on the board
+5V: J1.162, J1.173, J8.9, J8.10; also elsewhere on the board
+BATT: J1.115, J1.117, J1.119, J1.163, J1.164, J4.19, J7.13; also elsewhere on the board
/Connectors/PIN_37: J1.37, J6.19
/Connectors/PIN_38: J1.38, J6.17
/Connectors/PIN_39: J1.39, J6.15
/Connectors/PIN_40: J1.40, J6.13
/Connectors/PIN_41: J1.41, J6.11
/Connectors/PIN_42: J1.42, J6.9
/Connectors/PIN_43: J1.43, J6.7
/Connectors/PIN_44: J1.44, J4.20
/Connectors/PIN_45: J1.45, J7.17
/Connectors/PIN_46: J1.46, J7.19
/Connectors/PIN_47: J1.47, J7.15
/Connectors/PIN_48: J1.48, J7.12
/Connectors/PIN_49: J1.49, J7.11
/Connectors/PIN_50: J1.50, J6.20
/Connectors/PIN_51: J1.51, J6.18
/Connectors/PIN_52: J1.52, J6.16
/Connectors/PIN_53: J1.53, J6.14
/Connectors/PIN_54: J1.54, J6.12
/Connectors/PIN_55: J1.55, J6.10
/Connectors/PIN_56: J1.56, J6.8
/Connectors/PIN_57: J1.57, J4.18
/Connectors/PIN_58: J1.58, J4.16
/Connectors/PIN_59: J1.59, J4.14
/Connectors/PIN_60: J1.60, J7.14
/Connectors/PIN_61: J1.61, J7.10
/Connectors/PIN_62: J1.62, J7.9
/Connectors/PIN_63: J1.63, J3.19
/Connectors/PIN_64: J1.64, J3.17
/Connectors/PIN_65: J1.65, J3.15
/Connectors/PIN_66: J1.66, J3.13
/Connectors/PIN_67: J1.67, J3.11
/Connectors/PIN_68: J1.68, J3.9
/Connectors/PIN_69: J1.69, J3.7
/Connectors/PIN_70: J1.70, J4.17
/Connectors/PIN_71: J1.71, J4.11
/Connectors/PIN_72: J1.72, J4.9
/Connectors/PIN_73: J1.73, J4.7
/Connectors/PIN_74: J1.74, J7.8
/Connectors/PIN_75: J1.75, J7.7
/Connectors/PIN_76: J1.76, J3.20
/Connectors/PIN_77: J1.77, J3.18
/Connectors/PIN_78: J1.78, J3.16
/Connectors/PIN_79: J1.79, J3.14
/Connectors/PIN_80: J1.80, J3.12
/Connectors/PIN_81: J1.81, J3.10
/Connectors/PIN_82: J1.82, J3.8
/Connectors/PIN_83: J1.83, J4.15
/Connectors/PIN_84: J1.84, J4.8
/Connectors/PIN_85: J1.85, J4.6
/Connectors/PIN_86: J1.86, J4.5
/Connectors/PIN_87: J1.87, J7.6
/Connectors/PIN_88: J1.88, J7.5
/Connectors/PIN_89: J1.89, J6.5
/Connectors/PIN_90: J1.90, J6.6
/Connectors/PIN_91: J1.91, J6.3
/Connectors/PIN_92: J1.92, J3.6
/Connectors/PIN_93: J1.93, J3.5
/Connectors/PIN_94: J1.94, J7.20
/Connectors/PIN_95: J1.95, J7.18
/Connectors/PIN_96: J1.96, J4.13
/Connectors/PIN_97: J1.97, J4.10
/Connectors/PIN_98: J1.98, J4.4
/Connectors/PIN_99: J1.99, J4.3
/Connectors/PIN_100: J1.100, J7.4
/Connectors/PIN_101: J1.101, J7.3
/Connectors/PIN_102: J1.102, J3.2
/Connectors/PIN_103: J1.103, J3.4
/Connectors/PIN_104: J1.104, J3.3
/Connectors/PIN_105: J1.105, J3.1
/Connectors/PIN_106: J1.106, J6.4
/Connectors/PIN_107: J1.107, J6.2
/Connectors/PIN_108: J1.108, J6.1
/Connectors/PIN_109: J1.109, J4.12
/Connectors/PIN_110: J1.110, J7.16
/Connectors/PIN_111: J1.111, J4.2
/Connectors/PIN_112: J1.112, J4.1
/Connectors/PIN_113: J1.113, J7.2
/Connectors/PIN_114: J1.114, J7.1
/Connectors/PIN_121: J1.121, J5.29
/Connectors/PIN_122: J1.122, J5.26
/Connectors/PIN_123: J1.123, J5.23
/Connectors/PIN_132: J1.132, J5.28
/Connectors/PIN_133: J1.133, J5.27
/Connectors/PIN_134: J1.134, J5.24
/Connectors/PIN_135: J1.135, J5.15
/Connectors/PIN_136: J1.136, J5.14
/Connectors/PIN_143: J1.143, J5.31
/Connectors/PIN_144: J1.144, J5.30
/Connectors/PIN_145: J1.145, J5.25
/Connectors/PIN_146: J1.146, J5.17
/Connectors/PIN_147: J1.147, J5.16
/Connectors/PIN_154: J1.154, J5.34
/Connectors/PIN_155: J1.155, J5.33
/Connectors/PIN_156: J1.156, J5.32
/Connectors/PIN_157: J1.157, J5.19
/Connectors/PIN_158: J1.158, J5.18
/Connectors/PIN_165: J1.165, J5.36
/Connectors/PIN_166: J1.166, J5.37
/Connectors/PIN_167: J1.167, J5.35
/Connectors/PIN_168: J1.168, J5.21
/Connectors/PIN_169: J1.169, J5.20
/Connectors/PIN_170: J1.170, J5.11
/Connectors/PIN_176: J1.176, J5.40
/Connectors/PIN_177: J1.177, J5.38
/Connectors/PIN_178: J1.178, J5.39
/Connectors/PIN_181: J1.181, J5.22
/Connectors/PIN_182: J1.182, J5.9
CAN1_H: J9.28, J10.7; also elsewhere on the board
CAN1_L: J9.27, J10.2; also elsewhere on the board
CJ1251_CONN_HEATERGND: J1.152; also elsewhere on the board
CJ1251_CONN_IA: J1.174; also elsewhere on the board
CJ1251_CONN_IP: J1.130; also elsewhere on the board
CJ1251_CONN_UN: J1.185; also elsewhere on the board
CJ1251_CONN_VM: J1.141; also elsewhere on the board
CJ1251_HEATEROUT: J1.125, J5.12; also elsewhere on the board
CJ1251_MISO: J11.4; also elsewhere on the board
CJ1251_MOSI: J11.2; also elsewhere on the board
CJ1251_NSS: J11.3; also elsewhere on the board
CJ1251_SCK: J11.5; also elsewhere on the board
CJ1251_UA: J11.1; also elsewhere on the board
CJ1251_UR: J11.6; also elsewhere on the board
CJ1252_CONN_HEATERGND: J1.153; also elsewhere on the board
CJ1252_CONN_IA: J1.175; also elsewhere on the board
CJ1252_CONN_IP: J1.131; also elsewhere on the board
CJ1252_CONN_UN: J1.186; also elsewhere on the board
CJ1252_CONN_VM: J1.142; also elsewhere on the board
CJ1252_HEATEROUT: J1.124, J5.13; also elsewhere on the board
CJ1252_MISO: J12.4; also elsewhere on the board
CJ1252_MOSI: J12.2; also elsewhere on the board
CJ1252_NSS: J12.3; also elsewhere on the board
CJ1252_SCK: J12.5; also elsewhere on the board
CJ1252_UA: J12.1; also elsewhere on the board
CJ1252_UR: J12.6; also elsewhere on the board
COMP_IN7: J9.30; also elsewhere on the board
COMP_OUT7: J9.25; also elsewhere on the board
GND: J1.116, J1.118, J1.120, J8.3, J8.4, J9.29, J10.3, J10.5, J10.6, J10.10 (MH1), J10.11 (MH2); also elsewhere on the board
GPO_CUR1: J2.26; also elsewhere on the board
GPO_CUR2: J2.30; also elsewhere on the board
GPO_CUR3: J2.35; also elsewhere on the board
GPO_CUR4: J2.28; also elsewhere on the board
GPO_CUR5: J2.23; also elsewhere on the board
GPO_CUR6: J2.22; also elsewhere on the board
GPO_CUR7: J2.17; also elsewhere on the board
GPO_CUR8: J2.16; also elsewhere on the board
GPO_CUR9: J2.13; also elsewhere on the board
GPO_CUR10: J2.9; also elsewhere on the board
GPO_CUR11: J2.5; also elsewhere on the board
GPO_CUR12: J2.1; also elsewhere on the board
GPO_IN1: J2.27; also elsewhere on the board
GPO_IN2: J2.32; also elsewhere on the board
GPO_IN3: J2.31; also elsewhere on the board
GPO_IN4: J2.36; also elsewhere on the board
GPO_IN5: J2.21; also elsewhere on the board
GPO_IN6: J2.20; also elsewhere on the board
GPO_IN7: J2.15; also elsewhere on the board
GPO_IN8: J2.14; also elsewhere on the board
GPO_IN9: J2.10; also elsewhere on the board
GPO_IN10: J2.8; also elsewhere on the board
GPO_IN11: J2.3; also elsewhere on the board
GPO_IN12: J2.4; also elsewhere on the board
GPO_INH1: J2.25; also elsewhere on the board
GPO_INH2: J2.29; also elsewhere on the board
GPO_INH3: J2.33; also elsewhere on the board
GPO_INH4: J2.34; also elsewhere on the board
GPO_INH5: J2.24; also elsewhere on the board
GPO_INH6: J2.19; also elsewhere on the board
GPO_INH7: J2.18; also elsewhere on the board
GPO_INH8: J2.12; also elsewhere on the board
GPO_INH9: J2.11; also elsewhere on the board
GPO_INH10: J2.7; also elsewhere on the board
GPO_INH11: J2.6; also elsewhere on the board
GPO_INH12: J2.2; also elsewhere on the board
GPO_OUT1: J1.150; also elsewhere on the board
GPO_OUT2: J1.139; also elsewhere on the board
GPO_OUT3: J1.127; also elsewhere on the board
GPO_OUT4: J1.137; also elsewhere on the board
GPO_OUT5: J1.140; also elsewhere on the board
GPO_OUT6: J1.128; also elsewhere on the board
GPO_OUT7: J1.138; also elsewhere on the board
GPO_OUT8: J1.148; also elsewhere on the board
GPO_OUT9: J1.151; also elsewhere on the board
GPO_OUT10: J1.129; also elsewhere on the board
GPO_OUT11: J1.149; also elsewhere on the board
GPO_OUT12: J1.126; also elsewhere on the board
INJ1-: J1.1; also elsewhere on the board
INJ2-: J1.10; also elsewhere on the board
INJ3-: J1.2; also elsewhere on the board
INJ4-: J1.11; also elsewhere on the board
INJ5-: J1.3; also elsewhere on the board
INJ6-: J1.12; also elsewhere on the board
INJ7-: J1.4; also elsewhere on the board
INJ8-: J1.13; also elsewhere on the board
INJ9-: J1.5; also elsewhere on the board
INJ10-: J1.14; also elsewhere on the board
INJ11-: J1.6; also elsewhere on the board
INJ12+: J1.19, J1.28; also elsewhere on the board
INJ12-: J1.15; also elsewhere on the board
INJ34+: J1.20, J1.29; also elsewhere on the board
INJ56+: J1.21, J1.30; also elsewhere on the board
INJ78+: J1.22, J1.31; also elsewhere on the board
INJ910+: J1.23, J1.32; also elsewhere on the board
INJ1112+: J1.24, J1.33; also elsewhere on the board
PA9: J9.26; also elsewhere on the board
PA15: J9.24; also elsewhere on the board
PB3: J9.6; also elsewhere on the board
PB4: J9.7; also elsewhere on the board
PB5: J9.8; also elsewhere on the board
PB6: J9.9; also elsewhere on the board
PB7: J9.10; also elsewhere on the board
PB8: J9.11; also elsewhere on the board
PB9: J9.12; also elsewhere on the board
PC14: J9.13; also elsewhere on the board
PC15: J9.14; also elsewhere on the board
PD0: J9.22; also elsewhere on the board
PD1: J9.16; also elsewhere on the board
PD3: J9.1; also elsewhere on the board
PD4: J9.2; also elsewhere on the board
PD5: J9.3; also elsewhere on the board
PD6: J9.4; also elsewhere on the board
PD7: J9.5; also elsewhere on the board
PE7: J9.23; also elsewhere on the board
PF0: J9.20; also elsewhere on the board
PF1: J9.18; also elsewhere on the board
PF2: J9.21; also elsewhere on the board
PF9: J9.15; also elsewhere on the board
PF10: J9.17; also elsewhere on the board
PG10: J9.19; also elsewhere on the board
S4_RX: J8.12; also elsewhere on the board
S4_TX: J8.11; also elsewhere on the board
S5_RX: J8.14; also elsewhere on the board
S5_TX: J8.13; also elsewhere on the board
SPK1: J1.7; also elsewhere on the board
SPK2: J1.16; also elsewhere on the board
SPK3: J1.25; also elsewhere on the board
SPK4: J1.34; also elsewhere on the board
SPK5: J1.8; also elsewhere on the board
SPK6: J1.17; also elsewhere on the board
SPK7: J1.26; also elsewhere on the board
SPK8: J1.35; also elsewhere on the board
SPK9: J1.9; also elsewhere on the board
SPK10: J1.18; also elsewhere on the board
SPK11: J1.27; also elsewhere on the board
SPK12: J1.36; also elsewhere on the board
SWCLK: J8.6; also elsewhere on the board
SWDIO: J8.2; also elsewhere on the board
TMG_IN1: J1.179, J5.1; also elsewhere on the board
TMG_IN2: J1.161, J5.3; also elsewhere on the board
TMG_IN3: J1.183, J5.8; also elsewhere on the board
TMG_IN4: J1.159, J5.10; also elsewhere on the board
TMG_IN5: J1.171, J5.6; also elsewhere on the board
TMG_IN6: J1.180, J5.2; also elsewhere on the board
TMG_IN7: J1.160, J5.4; also elsewhere on the board
TMG_IN8: J1.184, J5.7; also elsewhere on the board
TMG_IN9: J1.172, J5.5; also elsewhere on the board

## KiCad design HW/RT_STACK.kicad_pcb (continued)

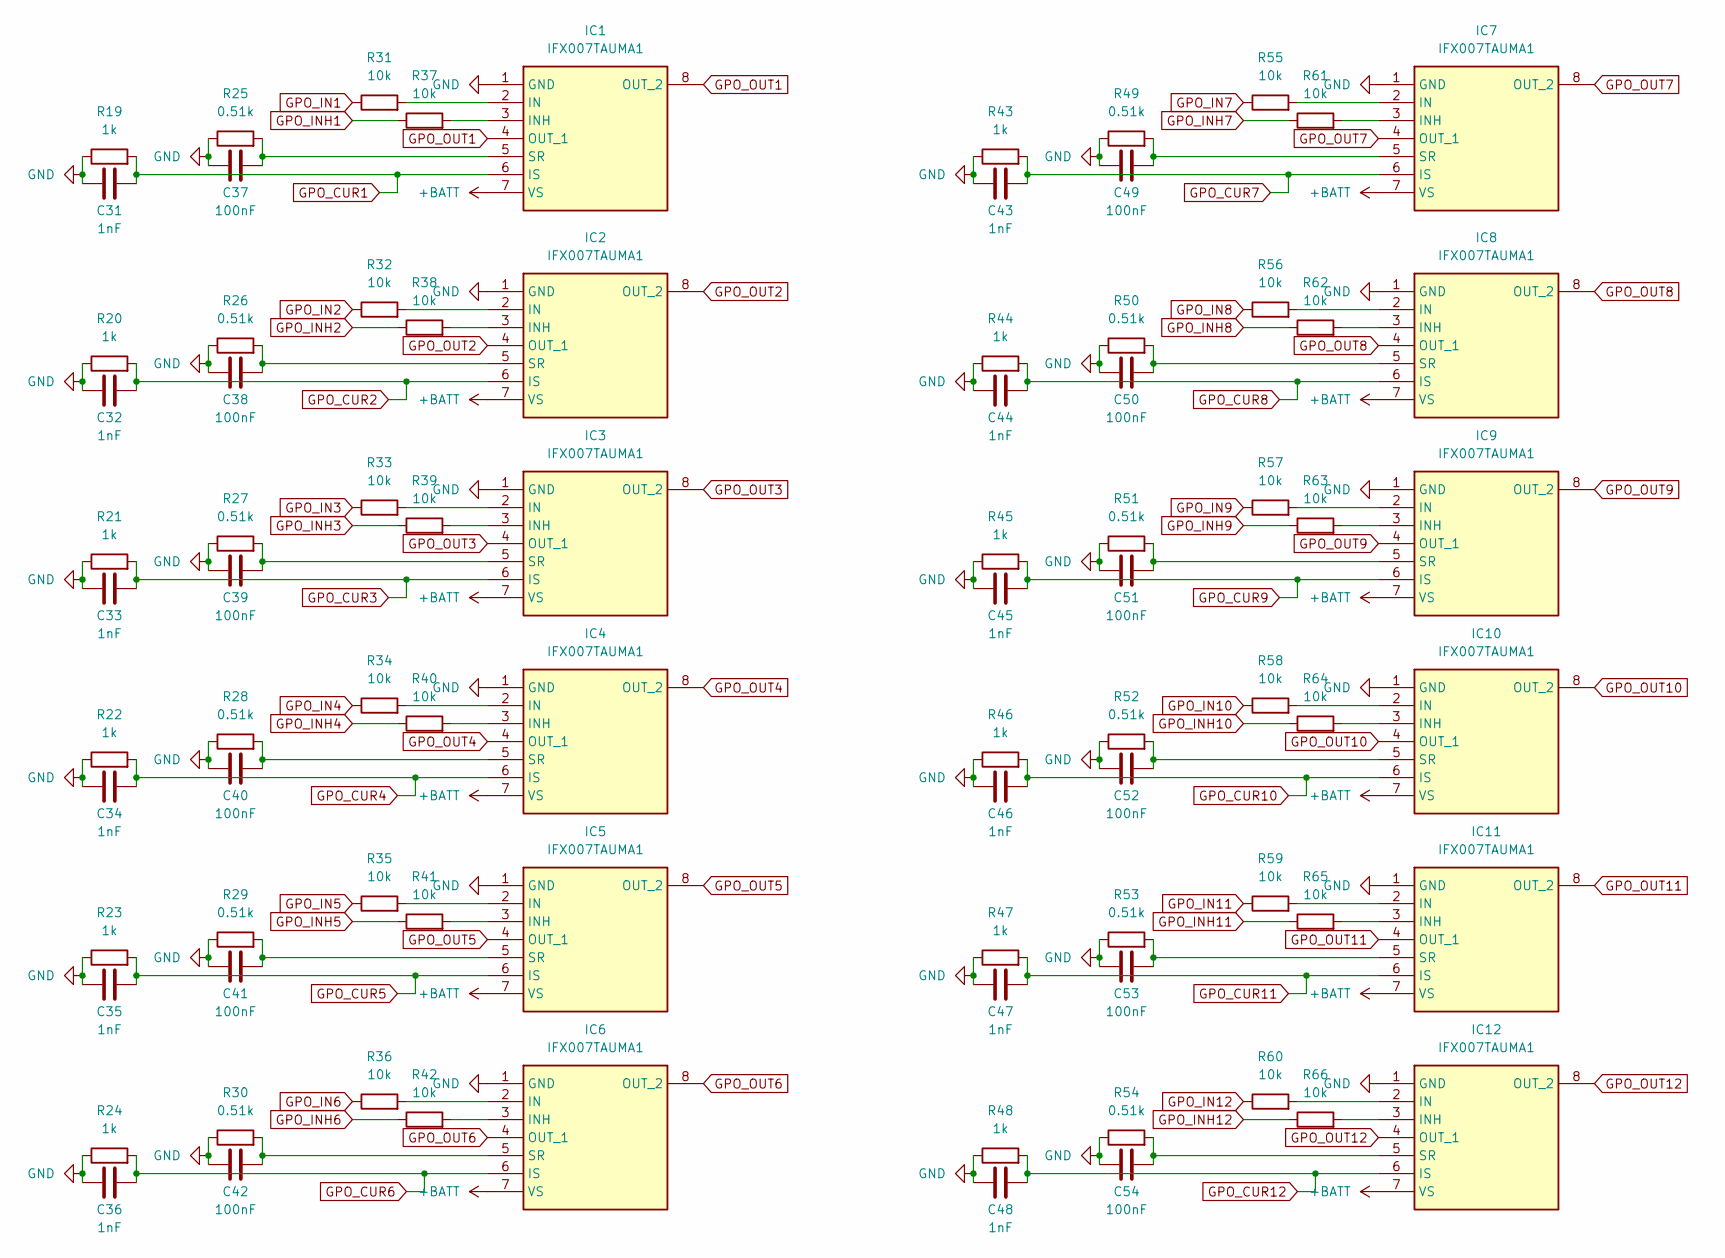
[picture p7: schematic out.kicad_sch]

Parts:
C31, C32, C33, C34, C35, C36, C43, C44, C45, C46, C47, C48: 1nF; C_0402_1005Metric
C37, C38, C39, C40, C41, C42, C49, C50, C51, C52, C53, C54: 100nF; C_0402_1005Metric
IC1, IC2, IC3, IC4, IC5, IC6, IC7, IC8, IC9, IC10, IC11, IC12: IFX007TAUMA1; PG-TO263-7-1; Mouser Part Number 726-IFX007TAUMA1
R19, R20, R21, R22, R23, R24, R43, R44, R45, R46, R47, R48: 1k; R_0402_1005Metric
R25, R26, R27, R28, R29, R30, R49, R50, R51, R52, R53, R54: 0.51k; R_0402_1005Metric
R31, R32, R33, R34, R35, R36, R37, R38, R39, R40, R41, R42, R55, R56, R57, R58, R59, R60, R61, R62, R63, R64, R65, R66: 10k; R_0402_1005Metric

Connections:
+BATT: IC1.7 (VS), IC2.7 (VS), IC3.7 (VS), IC4.7 (VS), IC5.7 (VS), IC6.7 (VS), IC7.7 (VS), IC8.7 (VS), IC9.7 (VS), IC10.7 (VS), IC11.7 (VS), IC12.7 (VS); also elsewhere on the board
GND: C31.1, C32.1, C33.1, C34.1, C35.1, C36.1, C37.1, C38.1, C39.1, C40.1, C41.1, C42.1, C43.1, C44.1, C45.1, C46.1, C47.1, C48.1, C49.1, C50.1, C51.1, C52.1, C53.1, C54.1, IC1.1 (GND), IC2.1 (GND), IC3.1 (GND), IC4.1 (GND), IC5.1 (GND), IC6.1 (GND), IC7.1 (GND), IC8.1 (GND), IC9.1 (GND), IC10.1 (GND), IC11.1 (GND), IC12.1 (GND), R19.1, R20.1, R21.1, R22.1, R23.1, R24.1, R25.1, R26.1, R27.1, R28.1, R29.1, R30.1, R43.1, R44.1, R45.1, R46.1, R47.1, R48.1, R49.1, R50.1, R51.1, R52.1, R53.1, R54.1; also elsewhere on the board
GPO_CUR1: C31.2, IC1.6 (IS), R19.2; also elsewhere on the board
GPO_CUR2: C32.2, IC2.6 (IS), R20.2; also elsewhere on the board
GPO_CUR3: C33.2, IC3.6 (IS), R21.2; also elsewhere on the board
GPO_CUR4: C34.2, IC4.6 (IS), R22.2; also elsewhere on the board
GPO_CUR5: C35.2, IC5.6 (IS), R23.2; also elsewhere on the board
GPO_CUR6: C36.2, IC6.6 (IS), R24.2; also elsewhere on the board
GPO_CUR7: C43.2, IC7.6 (IS), R43.2; also elsewhere on the board
GPO_CUR8: C44.2, IC8.6 (IS), R44.2; also elsewhere on the board
GPO_CUR9: C45.2, IC9.6 (IS), R45.2; also elsewhere on the board
GPO_CUR10: C46.2, IC10.6 (IS), R46.2; also elsewhere on the board
GPO_CUR11: C47.2, IC11.6 (IS), R47.2; also elsewhere on the board
GPO_CUR12: C48.2, IC12.6 (IS), R48.2; also elsewhere on the board
GPO_IN1: R31.1; also elsewhere on the board
GPO_IN2: R32.1; also elsewhere on the board
GPO_IN3: R33.1; also elsewhere on the board
GPO_IN4: R34.1; also elsewhere on the board
GPO_IN5: R35.1; also elsewhere on the board
GPO_IN6: R36.1; also elsewhere on the board
GPO_IN7: R55.1; also elsewhere on the board
GPO_IN8: R56.1; also elsewhere on the board
GPO_IN9: R57.1; also elsewhere on the board
GPO_IN10: R58.1; also elsewhere on the board
GPO_IN11: R59.1; also elsewhere on the board
GPO_IN12: R60.1; also elsewhere on the board
GPO_INH1: R37.1; also elsewhere on the board
GPO_INH2: R38.1; also elsewhere on the board
GPO_INH3: R39.1; also elsewhere on the board
GPO_INH4: R40.1; also elsewhere on the board
GPO_INH5: R41.1; also elsewhere on the board
GPO_INH6: R42.1; also elsewhere on the board
GPO_INH7: R61.1; also elsewhere on the board
GPO_INH8: R62.1; also elsewhere on the board
GPO_INH9: R63.1; also elsewhere on the board
GPO_INH10: R64.1; also elsewhere on the board
GPO_INH11: R65.1; also elsewhere on the board
GPO_INH12: R66.1; also elsewhere on the board
GPO_OUT1: IC1.4 (OUT_1), IC1.8 (OUT_2); also elsewhere on the board
GPO_OUT2: IC2.4 (OUT_1), IC2.8 (OUT_2); also elsewhere on the board
GPO_OUT3: IC3.4 (OUT_1), IC3.8 (OUT_2); also elsewhere on the board
GPO_OUT4: IC4.4 (OUT_1), IC4.8 (OUT_2); also elsewhere on the board
GPO_OUT5: IC5.4 (OUT_1), IC5.8 (OUT_2); also elsewhere on the board
GPO_OUT6: IC6.4 (OUT_1), IC6.8 (OUT_2); also elsewhere on the board
GPO_OUT7: IC7.4 (OUT_1), IC7.8 (OUT_2); also elsewhere on the board
GPO_OUT8: IC8.4 (OUT_1), IC8.8 (OUT_2); also elsewhere on the board
GPO_OUT9: IC9.4 (OUT_1), IC9.8 (OUT_2); also elsewhere on the board
GPO_OUT10: IC10.4 (OUT_1), IC10.8 (OUT_2); also elsewhere on the board
GPO_OUT11: IC11.4 (OUT_1), IC11.8 (OUT_2); also elsewhere on the board
GPO_OUT12: IC12.4 (OUT_1), IC12.8 (OUT_2); also elsewhere on the board
unnamed: IC1.2 (IN), R31.2
unnamed: IC1.3 (INH), R37.2
unnamed: C37.2, IC1.5 (SR), R25.2
unnamed: IC2.2 (IN), R32.2
unnamed: IC2.3 (INH), R38.2
unnamed: C38.2, IC2.5 (SR), R26.2
unnamed: IC3.2 (IN), R33.2
unnamed: IC3.3 (INH), R39.2
unnamed: C39.2, IC3.5 (SR), R27.2
unnamed: IC4.2 (IN), R34.2
unnamed: IC4.3 (INH), R40.2
unnamed: C40.2, IC4.5 (SR), R28.2
unnamed: IC5.2 (IN), R35.2
unnamed: IC5.3 (INH), R41.2
unnamed: C41.2, IC5.5 (SR), R29.2
unnamed: IC6.2 (IN), R36.2
unnamed: IC6.3 (INH), R42.2
unnamed: C42.2, IC6.5 (SR), R30.2
unnamed: IC7.2 (IN), R55.2
unnamed: IC7.3 (INH), R61.2
unnamed: C49.2, IC7.5 (SR), R49.2
unnamed: IC8.2 (IN), R56.2
unnamed: IC8.3 (INH), R62.2
unnamed: C50.2, IC8.5 (SR), R50.2
unnamed: IC9.2 (IN), R57.2
unnamed: IC9.3 (INH), R63.2
unnamed: C51.2, IC9.5 (SR), R51.2
unnamed: IC10.2 (IN), R58.2
unnamed: IC10.3 (INH), R64.2
unnamed: C52.2, IC10.5 (SR), R52.2
unnamed: IC11.2 (IN), R59.2
unnamed: IC11.3 (INH), R65.2
unnamed: C53.2, IC11.5 (SR), R53.2
unnamed: IC12.2 (IN), R60.2
unnamed: IC12.3 (INH), R66.2
unnamed: C54.2, IC12.5 (SR), R54.2

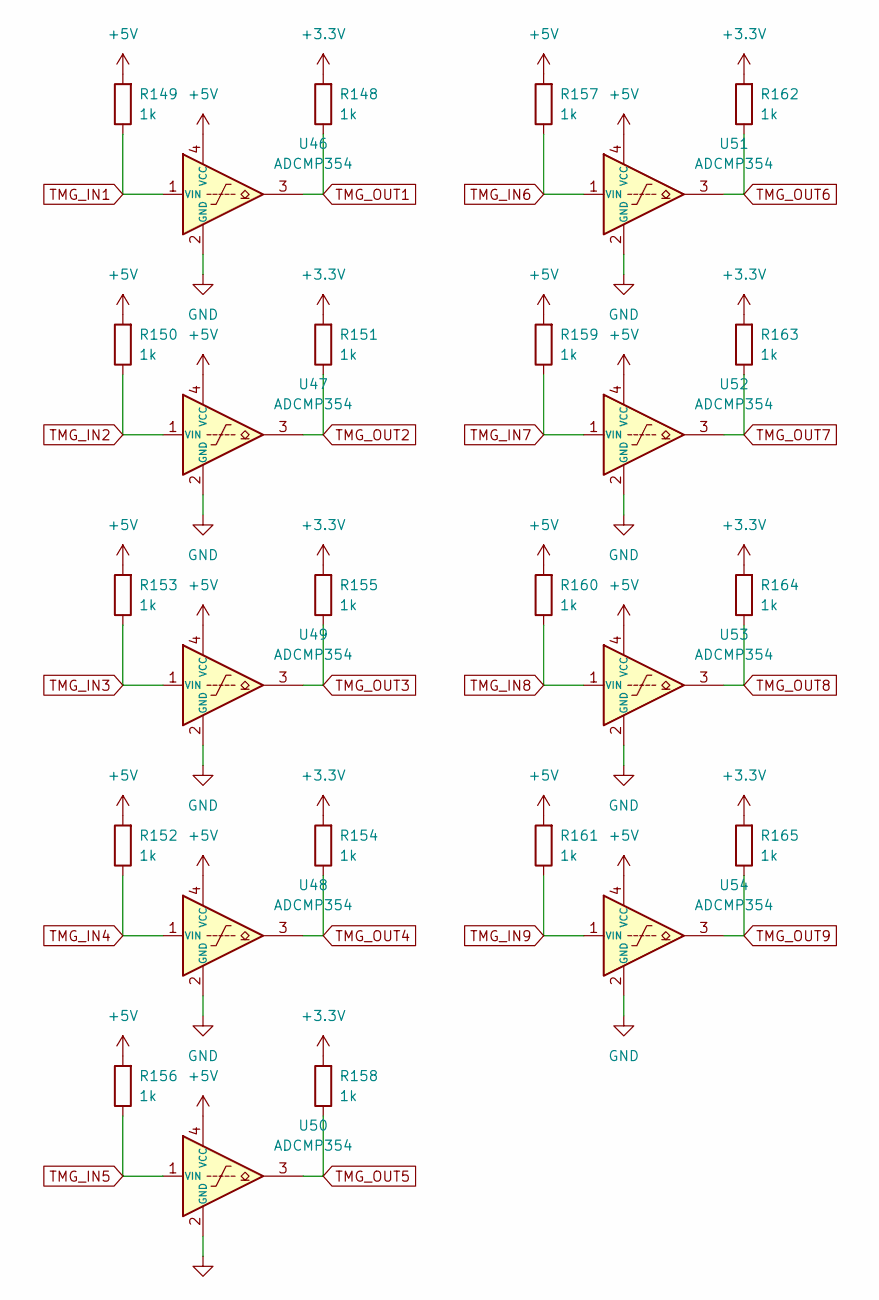
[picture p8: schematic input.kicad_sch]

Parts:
R148, R151, R154, R155, R158, R162, R163, R164, R165: 1k; R_0402_1005Metric
R149, R150, R152, R153, R156, R157, R159, R160, R161: 1k; R_Axial_DIN0204_L3.6mm_D1.6mm_P1.90mm_Vertical
U46, U47, U48, U49, U50, U51, U52, U53, U54: ADCMP354; Analog_KS-4

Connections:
+3.3V: R148.2, R151.2, R154.2, R155.2, R158.2, R162.2, R163.2, R164.2, R165.2; also elsewhere on the board
+5V: R149.2, R150.2, R152.2, R153.2, R156.2, R157.2, R159.2, R160.2, R161.2, U46.4 (VCC), U47.4 (VCC), U48.4 (VCC), U49.4 (VCC), U50.4 (VCC), U51.4 (VCC), U52.4 (VCC), U53.4 (VCC), U54.4 (VCC); also elsewhere on the board
GND: U46.2 (GND), U47.2 (GND), U48.2 (GND), U49.2 (GND), U50.2 (GND), U51.2 (GND), U52.2 (GND), U53.2 (GND), U54.2 (GND); also elsewhere on the board
TMG_IN1: R149.1, U46.1 (VIN); also elsewhere on the board
TMG_IN2: R150.1, U47.1 (VIN); also elsewhere on the board
TMG_IN3: R153.1, U49.1 (VIN); also elsewhere on the board
TMG_IN4: R152.1, U48.1 (VIN); also elsewhere on the board
TMG_IN5: R156.1, U50.1 (VIN); also elsewhere on the board
TMG_IN6: R157.1, U51.1 (VIN); also elsewhere on the board
TMG_IN7: R159.1, U52.1 (VIN); also elsewhere on the board
TMG_IN8: R160.1, U53.1 (VIN); also elsewhere on the board
TMG_IN9: R161.1, U54.1 (VIN); also elsewhere on the board
TMG_OUT1: R148.1, U46.3; also elsewhere on the board
TMG_OUT2: R151.1, U47.3; also elsewhere on the board
TMG_OUT3: R155.1, U49.3; also elsewhere on the board
TMG_OUT4: R154.1, U48.3; also elsewhere on the board
TMG_OUT5: R158.1, U50.3; also elsewhere on the board
TMG_OUT6: R162.1, U51.3; also elsewhere on the board
TMG_OUT7: R163.1, U52.3; also elsewhere on the board
TMG_OUT8: R164.1, U53.3; also elsewhere on the board
TMG_OUT9: R165.1, U54.3; also elsewhere on the board

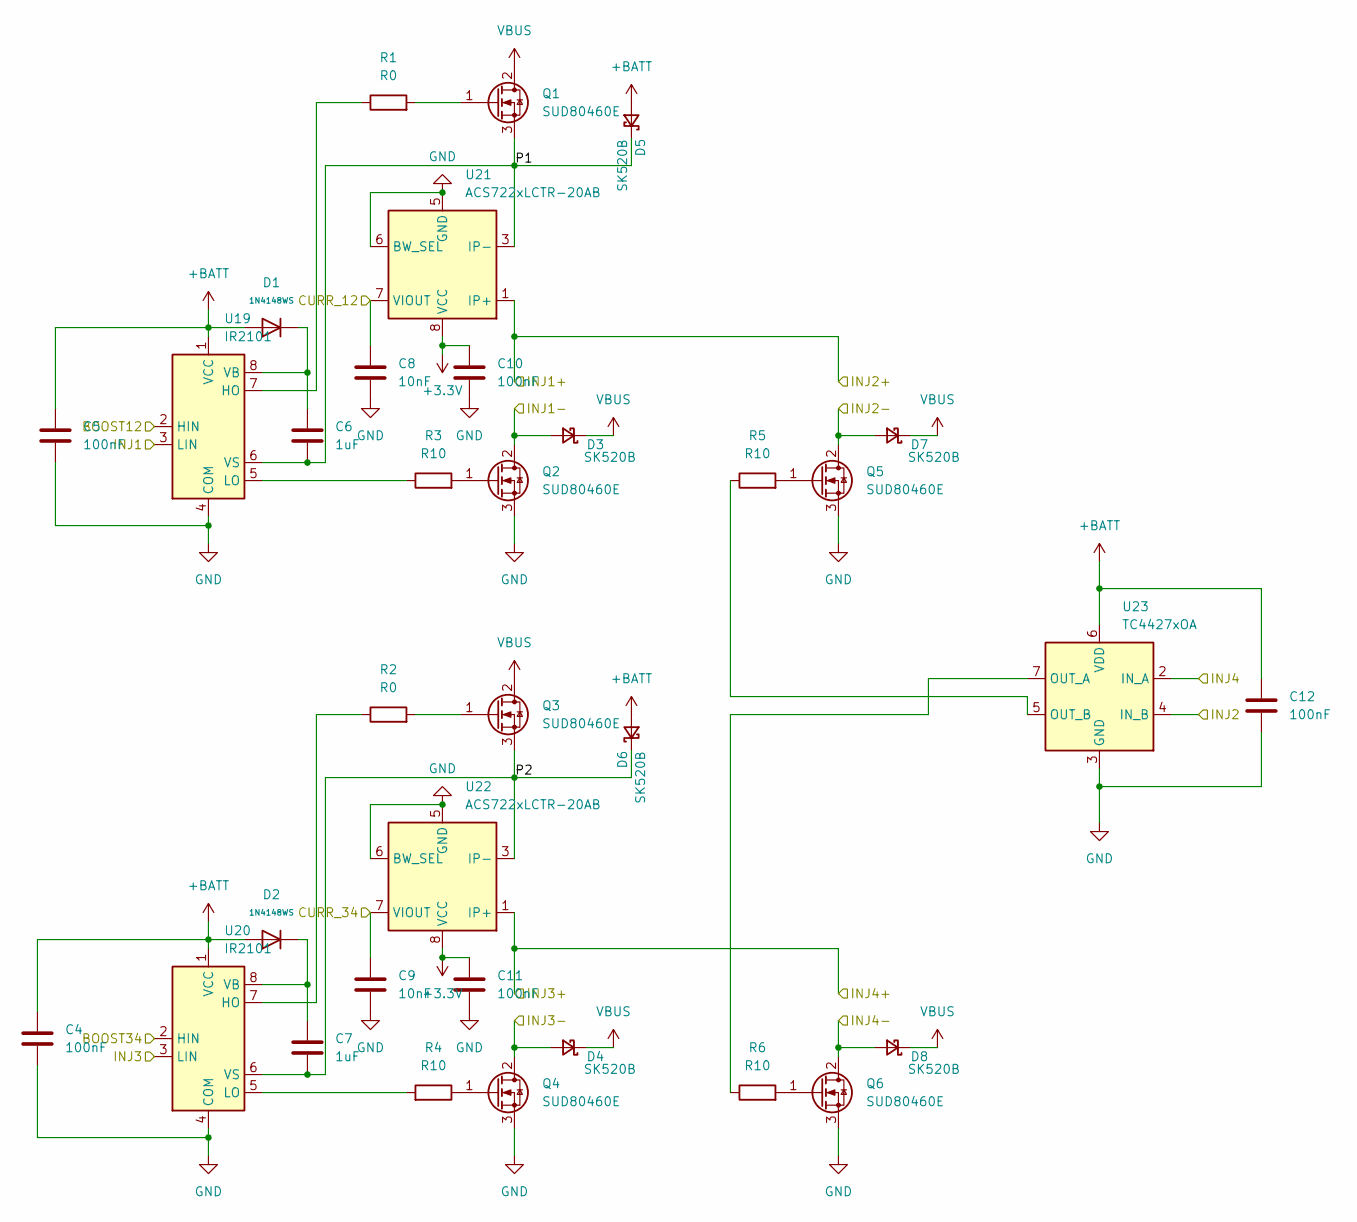
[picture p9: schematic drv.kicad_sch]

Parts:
C4, C5, C10, C11, C12: 100nF; C_0402_1005Metric
C6, C7: 1uF; C_0402_1005Metric
C8, C9: 10nF; C_0402_1005Metric
D1, D2: 1N4148WS; D_SOD-323; Forward Voltage (Vf@If) 1.25V@150mA; Reverse Voltage (Vr) 100V; Part 1N4148WS; LCSC C2128
D3, D4, D5, D6, D7, D8: SK520B; D_SMB; LCSC C139681
Q1, Q2, Q3, Q4, Q5, Q6: SUD80460E; TO-252-2
R1, R2: R0; R_0402_1005Metric
R3, R4, R5, R6: R10; R_0402_1005Metric
U19, U20: IR2101; SOIC-8_3.9x4.9mm_P1.27mm
U21, U22: ACS722xLCTR-20AB; SOIC-8_3.9x4.9mm_P1.27mm
U23: TC4427xOA; SOIC-8_3.9x4.9mm_P1.27mm; JLC C640788

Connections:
+3.3V: C10.1, C11.1, U21.8 (VCC), U22.8 (VCC); also elsewhere on the board
+BATT: C4.1, C5.1, C12.1, D1.2, D2.2, D5.2 (A), D6.2 (A), U19.1 (VCC), U20.1 (VCC), U23.6 (VDD); also elsewhere on the board
/Inj Drivers/GDI BANK 2/P1: C6.2, D5.1 (K), Q1.3 (S), U19.6 (VS), U21.3 (IP-), U21.4 (IP-)
/Inj Drivers/GDI BANK 2/P2: C7.2, D6.1 (K), Q3.3 (S), U20.6 (VS), U22.3 (IP-), U22.4 (IP-)
/Inj Drivers/INJ5_L: U19.3 (LIN); also elsewhere on the board
/Inj Drivers/INJ6_L: U23.4 (IN_B); also elsewhere on the board
/Inj Drivers/INJ7_L: U20.3 (LIN); also elsewhere on the board
/Inj Drivers/INJ8_L: U23.2 (IN_A); also elsewhere on the board
BOOST56: U19.2 (HIN); also elsewhere on the board
BOOST78: U20.2 (HIN); also elsewhere on the board
COMP_IN3: C8.1, U21.7 (VIOUT); also elsewhere on the board
COMP_IN4: C9.1, U22.7 (VIOUT); also elsewhere on the board
GND: C4.2, C5.2, C8.2, C9.2, C10.2, C11.2, C12.2, Q2.3 (S), Q4.3 (S), Q5.3 (S), Q6.3 (S), U19.4 (COM), U20.4 (COM), U21.5 (GND), U21.6 (BW_SEL), U22.5 (GND), U22.6 (BW_SEL), U23.3 (GND); also elsewhere on the board
INJ5-: D3.2 (A), Q2.2 (D); also elsewhere on the board
INJ6-: D7.2 (A), Q5.2 (D); also elsewhere on the board
INJ7-: D4.2 (A), Q4.2 (D); also elsewhere on the board
INJ8-: D8.2 (A), Q6.2 (D); also elsewhere on the board
INJ56+: U21.1 (IP+), U21.2 (IP+); also elsewhere on the board
INJ78+: U22.1 (IP+), U22.2 (IP+); also elsewhere on the board
unnamed: Q1.1 (G), R1.2
unnamed: Q2.1 (G), R3.2
unnamed: Q3.1 (G), R2.2
unnamed: Q4.1 (G), R4.1
unnamed: Q5.1 (G), R5.2
unnamed: Q6.1 (G), R6.2
unnamed: R1.1, U19.7 (HO)
unnamed: R3.1, U19.5 (LO)
unnamed: C6.1, D1.1, U19.8 (VB)
unnamed: R2.1, U20.7 (HO)
unnamed: R4.2, U20.5 (LO)
unnamed: C7.1, D2.1, U20.8 (VB)
unnamed: R6.1, U23.7 (OUT_A)
unnamed: R5.1, U23.5 (OUT_B)
VBUS: D3.1 (K), D4.1 (K), D7.1 (K), D8.1 (K), Q1.2 (D), Q3.2 (D); also elsewhere on the board

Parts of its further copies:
C13, C14, C19, C20, C21, C22, C23, C28, C29, C30: 100nF; C_0402_1005Metric
C15, C16, C24, C25: 1uF; C_0402_1005Metric
C17, C18, C26, C27: 10nF; C_0402_1005Metric
D9, D10, D17, D18: 1N4148WS; D_SOD-323; Forward Voltage (Vf@If) 1.25V@150mA; Reverse Voltage (Vr) 100V; Part 1N4148WS; LCSC C2128
D11, D12, D13, D14, D15, D16, D19, D20, D21, D22, D23, D24: SK520B; D_SMB; LCSC C139681
Q7, Q8, Q9, Q10, Q11, Q12, Q13, Q14, Q15, Q16, Q17, Q18: SUD80460E; TO-252-2
R7, R8, R13, R14: R0; R_0402_1005Metric
R9, R10, R11, R12, R15, R16, R17, R18: R10; R_0402_1005Metric
U24, U25, U29, U30: IR2101; SOIC-8_3.9x4.9mm_P1.27mm
U26, U27, U31, U32: ACS722xLCTR-20AB; SOIC-8_3.9x4.9mm_P1.27mm
U28, U33: TC4427xOA; SOIC-8_3.9x4.9mm_P1.27mm; JLC C640788

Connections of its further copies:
+3.3V: C19.1, C20.1, C28.1, C29.1, U26.8 (VCC), U27.8 (VCC), U31.8 (VCC), U32.8 (VCC); also elsewhere on the board
+BATT: C13.1, C14.1, C21.1, C22.1, C23.1, C30.1, D9.2, D10.2, D13.2 (A), D14.2 (A), D17.2, D18.2, D21.2 (A), D22.2 (A), U24.1 (VCC), U25.1 (VCC), U28.6 (VDD), U29.1 (VCC), U30.1 (VCC), U33.6 (VDD); also elsewhere on the board
/Inj Drivers/GDI BANK1/P1: C24.2, D21.1 (K), Q13.3 (S), U29.6 (VS), U31.3 (IP-), U31.4 (IP-)
/Inj Drivers/GDI BANK1/P2: C25.2, D22.1 (K), Q15.3 (S), U30.6 (VS), U32.3 (IP-), U32.4 (IP-)
/Inj Drivers/GDI BANK 3/P1: C15.2, D13.1 (K), Q7.3 (S), U24.6 (VS), U26.3 (IP-), U26.4 (IP-)
/Inj Drivers/GDI BANK 3/P2: C16.2, D14.1 (K), Q9.3 (S), U25.6 (VS), U27.3 (IP-), U27.4 (IP-)
/Inj Drivers/INJ1_L: U29.3 (LIN); also elsewhere on the board
/Inj Drivers/INJ2_L: U33.4 (IN_B); also elsewhere on the board
/Inj Drivers/INJ3_L: U30.3 (LIN); also elsewhere on the board
/Inj Drivers/INJ4_L: U33.2 (IN_A); also elsewhere on the board
/Inj Drivers/INJ9_L: U24.3 (LIN); also elsewhere on the board
/Inj Drivers/INJ10_L: U28.4 (IN_B); also elsewhere on the board
/Inj Drivers/INJ11_L: U25.3 (LIN); also elsewhere on the board
/Inj Drivers/INJ12_L: U28.2 (IN_A); also elsewhere on the board
BOOST12: U29.2 (HIN); also elsewhere on the board
BOOST34: U30.2 (HIN); also elsewhere on the board
BOOST910: U24.2 (HIN); also elsewhere on the board
BOOST1112: U25.2 (HIN); also elsewhere on the board
COMP_IN1: C26.1, U31.7 (VIOUT); also elsewhere on the board
COMP_IN2: C27.1, U32.7 (VIOUT); also elsewhere on the board
COMP_IN5: C17.1, U26.7 (VIOUT); also elsewhere on the board
COMP_IN6: C18.1, U27.7 (VIOUT); also elsewhere on the board
GND: C13.2, C14.2, C17.2, C18.2, C19.2, C20.2, C21.2, C22.2, C23.2, C26.2, C27.2, C28.2, C29.2, C30.2, Q8.3 (S), Q10.3 (S), Q11.3 (S), Q12.3 (S), Q14.3 (S), Q16.3 (S), Q17.3 (S), Q18.3 (S), U24.4 (COM), U25.4 (COM), U26.5 (GND), U26.6 (BW_SEL), U27.5 (GND), U27.6 (BW_SEL), U28.3 (GND), U29.4 (COM), U30.4 (COM), U31.5 (GND), U31.6 (BW_SEL), U32.5 (GND), U32.6 (BW_SEL), U33.3 (GND); also elsewhere on the board
INJ1-: D19.2 (A), Q14.2 (D); also elsewhere on the board
INJ2-: D23.2 (A), Q17.2 (D); also elsewhere on the board
INJ3-: D20.2 (A), Q16.2 (D); also elsewhere on the board
INJ4-: D24.2 (A), Q18.2 (D); also elsewhere on the board
INJ9-: D11.2 (A), Q8.2 (D); also elsewhere on the board
INJ10-: D15.2 (A), Q11.2 (D); also elsewhere on the board
INJ11-: D12.2 (A), Q10.2 (D); also elsewhere on the board
INJ12+: U31.1 (IP+), U31.2 (IP+); also elsewhere on the board
INJ12-: D16.2 (A), Q12.2 (D); also elsewhere on the board
INJ34+: U32.1 (IP+), U32.2 (IP+); also elsewhere on the board
INJ910+: U26.1 (IP+), U26.2 (IP+); also elsewhere on the board
INJ1112+: U27.1 (IP+), U27.2 (IP+); also elsewhere on the board
unnamed: Q7.1 (G), R7.2
unnamed: Q8.1 (G), R9.2
unnamed: Q9.1 (G), R8.2
unnamed: Q10.1 (G), R10.1
unnamed: Q11.1 (G), R11.2
unnamed: Q12.1 (G), R12.2
unnamed: Q13.1 (G), R13.2
unnamed: Q14.1 (G), R15.2
unnamed: Q15.1 (G), R14.2
unnamed: Q16.1 (G), R16.1
unnamed: Q17.1 (G), R17.2
unnamed: Q18.1 (G), R18.2
unnamed: R7.1, U24.7 (HO)
unnamed: R9.1, U24.5 (LO)
unnamed: C15.1, D9.1, U24.8 (VB)
unnamed: R8.1, U25.7 (HO)
unnamed: R10.2, U25.5 (LO)
unnamed: C16.1, D10.1, U25.8 (VB)
unnamed: R12.1, U28.7 (OUT_A)
unnamed: R11.1, U28.5 (OUT_B)
unnamed: R13.1, U29.7 (HO)
unnamed: R15.1, U29.5 (LO)
unnamed: C24.1, D17.1, U29.8 (VB)
unnamed: R14.1, U30.7 (HO)
unnamed: R16.2, U30.5 (LO)
unnamed: C25.1, D18.1, U30.8 (VB)
unnamed: R18.1, U33.7 (OUT_A)
unnamed: R17.1, U33.5 (OUT_B)
VBUS: D11.1 (K), D12.1 (K), D15.1 (K), D16.1 (K), D19.1 (K), D20.1 (K), D23.1 (K), D24.1 (K), Q7.2 (D), Q9.2 (D), Q13.2 (D), Q15.2 (D); also elsewhere on the board

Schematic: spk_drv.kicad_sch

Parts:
C55: 100nF; C_0402_1005Metric
C56, C57: 220nF; C_0402_1005Metric
D25, D26, D27, D28: SK520B; D_SMB; LCSC C139681
Q19, Q20: RGPR30BM40; TO-252-2
R67, R68, R69, R70: 10; R_0402_1005Metric
U34: TC4427xOA; SOIC-8_3.9x4.9mm_P1.27mm; JLC C640788

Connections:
+5V: C55.1, U34.6 (VDD); also elsewhere on the board
+BATT: D25.1 (K), D27.1 (K); also elsewhere on the board
GND: C55.2, D26.2 (A), D28.2 (A), Q19.3 (E), Q20.3 (E), R69.1, R70.1, U34.3 (GND); also elsewhere on the board
IGN1: U34.2 (IN_A); also elsewhere on the board
IGN2: U34.4 (IN_B); also elsewhere on the board
unnamed: C56.2, R69.2
unnamed: C57.2, R70.2
unnamed: Q19.1 (G), R67.1
unnamed: Q20.1 (G), R68.1
unnamed: R67.2, U34.7 (OUT_A)
unnamed: R68.2, U34.5 (OUT_B)
SPK1: C57.1, D27.2 (A), D28.1 (K), Q20.2 (C); also elsewhere on the board
SPK2: C56.1, D25.2 (A), D26.1 (K), Q19.2 (C); also elsewhere on the board

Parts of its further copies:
C58, C61, C64, C67, C70: 100nF; C_0402_1005Metric
C59, C60, C62, C63, C65, C66, C68, C69, C71, C72: 220nF; C_0402_1005Metric
D29, D30, D31, D32, D33, D34, D35, D36, D37, D38, D39, D40, D41, D42, D43, D44, D45, D46, D47, D48: SK520B; D_SMB; LCSC C139681
Q21, Q22, Q23, Q24, Q25, Q26, Q27, Q28, Q29, Q30: RGPR30BM40; TO-252-2
R71, R72, R73, R74, R75, R76, R77, R78, R79, R80, R81, R82, R83, R84, R85, R86, R87, R88, R89, R90: 10; R_0402_1005Metric
U35, U36, U37, U38, U39: TC4427xOA; SOIC-8_3.9x4.9mm_P1.27mm; JLC C640788

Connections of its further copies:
+5V: C58.1, C61.1, C64.1, C67.1, C70.1, U35.6 (VDD), U36.6 (VDD), U37.6 (VDD), U38.6 (VDD), U39.6 (VDD); also elsewhere on the board
+BATT: D29.1 (K), D31.1 (K), D33.1 (K), D35.1 (K), D37.1 (K), D39.1 (K), D41.1 (K), D43.1 (K), D45.1 (K), D47.1 (K); also elsewhere on the board
GND: C58.2, C61.2, C64.2, C67.2, C70.2, D30.2 (A), D32.2 (A), D34.2 (A), D36.2 (A), D38.2 (A), D40.2 (A), D42.2 (A), D44.2 (A), D46.2 (A), D48.2 (A), Q21.3 (E), Q22.3 (E), Q23.3 (E), Q24.3 (E), Q25.3 (E), Q26.3 (E), Q27.3 (E), Q28.3 (E), Q29.3 (E), Q30.3 (E), R73.1, R74.1, R77.1, R78.1, R81.1, R82.1, R85.1, R86.1, R89.1, R90.1, U35.3 (GND), U36.3 (GND), U37.3 (GND), U38.3 (GND), U39.3 (GND); also elsewhere on the board
IGN3: U35.2 (IN_A); also elsewhere on the board
IGN4: U35.4 (IN_B); also elsewhere on the board
IGN5: U36.2 (IN_A); also elsewhere on the board
IGN6: U36.4 (IN_B); also elsewhere on the board
IGN7: U37.2 (IN_A); also elsewhere on the board
IGN8: U37.4 (IN_B); also elsewhere on the board
IGN9: U38.2 (IN_A); also elsewhere on the board
IGN10: U38.4 (IN_B); also elsewhere on the board
IGN11: U39.2 (IN_A); also elsewhere on the board
IGN12: U39.4 (IN_B); also elsewhere on the board
unnamed: C59.2, R73.2
unnamed: C60.2, R74.2
unnamed: C62.2, R77.2
unnamed: C63.2, R78.2
unnamed: C65.2, R81.2
unnamed: C66.2, R82.2
unnamed: C68.2, R85.2
unnamed: C69.2, R86.2
unnamed: C71.2, R89.2
unnamed: C72.2, R90.2
unnamed: Q21.1 (G), R71.1
unnamed: Q22.1 (G), R72.1
unnamed: Q23.1 (G), R75.1
unnamed: Q24.1 (G), R76.1
unnamed: Q25.1 (G), R79.1
unnamed: Q26.1 (G), R80.1
unnamed: Q27.1 (G), R83.1
unnamed: Q28.1 (G), R84.1
unnamed: Q29.1 (G), R87.1
unnamed: Q30.1 (G), R88.1
unnamed: R71.2, U35.7 (OUT_A)
unnamed: R72.2, U35.5 (OUT_B)
unnamed: R75.2, U36.7 (OUT_A)
unnamed: R76.2, U36.5 (OUT_B)
unnamed: R79.2, U37.7 (OUT_A)
unnamed: R80.2, U37.5 (OUT_B)
unnamed: R83.2, U38.7 (OUT_A)
unnamed: R84.2, U38.5 (OUT_B)
unnamed: R87.2, U39.7 (OUT_A)
unnamed: R88.2, U39.5 (OUT_B)
SPK3: C60.1, D31.2 (A), D32.1 (K), Q22.2 (C); also elsewhere on the board
SPK4: C59.1, D29.2 (A), D30.1 (K), Q21.2 (C); also elsewhere on the board
SPK5: C63.1, D35.2 (A), D36.1 (K), Q24.2 (C); also elsewhere on the board
SPK6: C62.1, D33.2 (A), D34.1 (K), Q23.2 (C); also elsewhere on the board
SPK7: C66.1, D39.2 (A), D40.1 (K), Q26.2 (C); also elsewhere on the board
SPK8: C65.1, D37.2 (A), D38.1 (K), Q25.2 (C); also elsewhere on the board
SPK9: C69.1, D43.2 (A), D44.1 (K), Q28.2 (C); also elsewhere on the board
SPK10: C68.1, D41.2 (A), D42.1 (K), Q27.2 (C); also elsewhere on the board
SPK11: C72.1, D47.2 (A), D48.1 (K), Q30.2 (C); also elsewhere on the board
SPK12: C71.1, D45.2 (A), D46.1 (K), Q29.2 (C); also elsewhere on the board

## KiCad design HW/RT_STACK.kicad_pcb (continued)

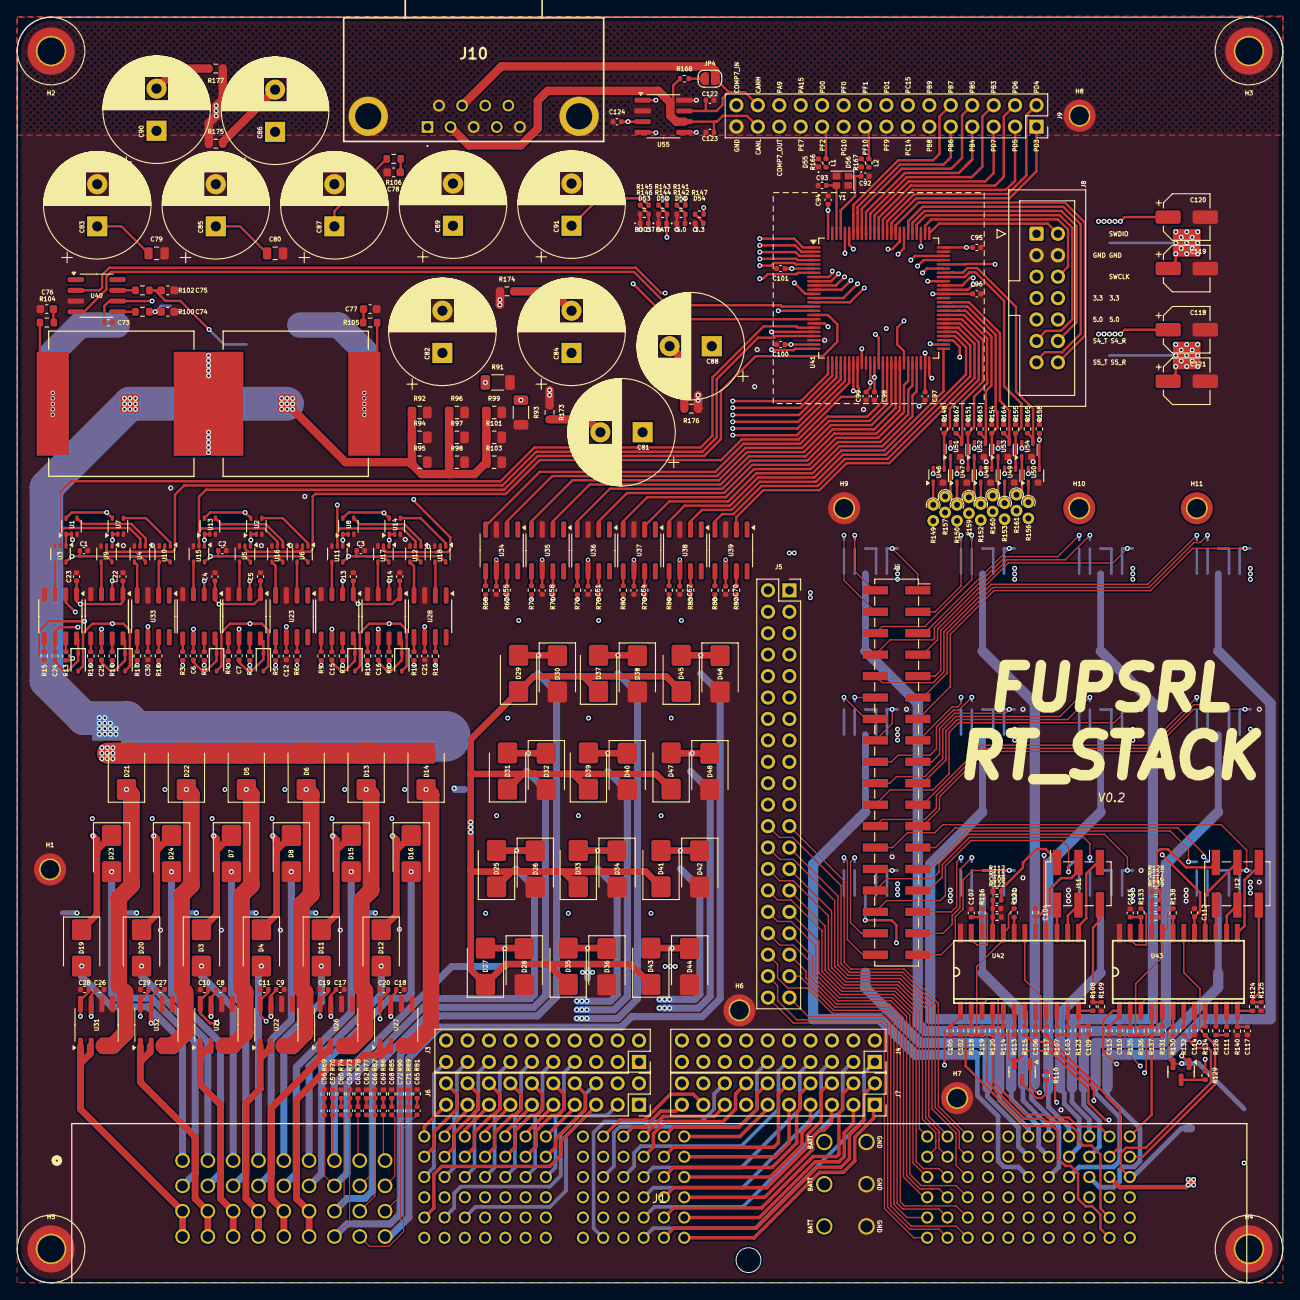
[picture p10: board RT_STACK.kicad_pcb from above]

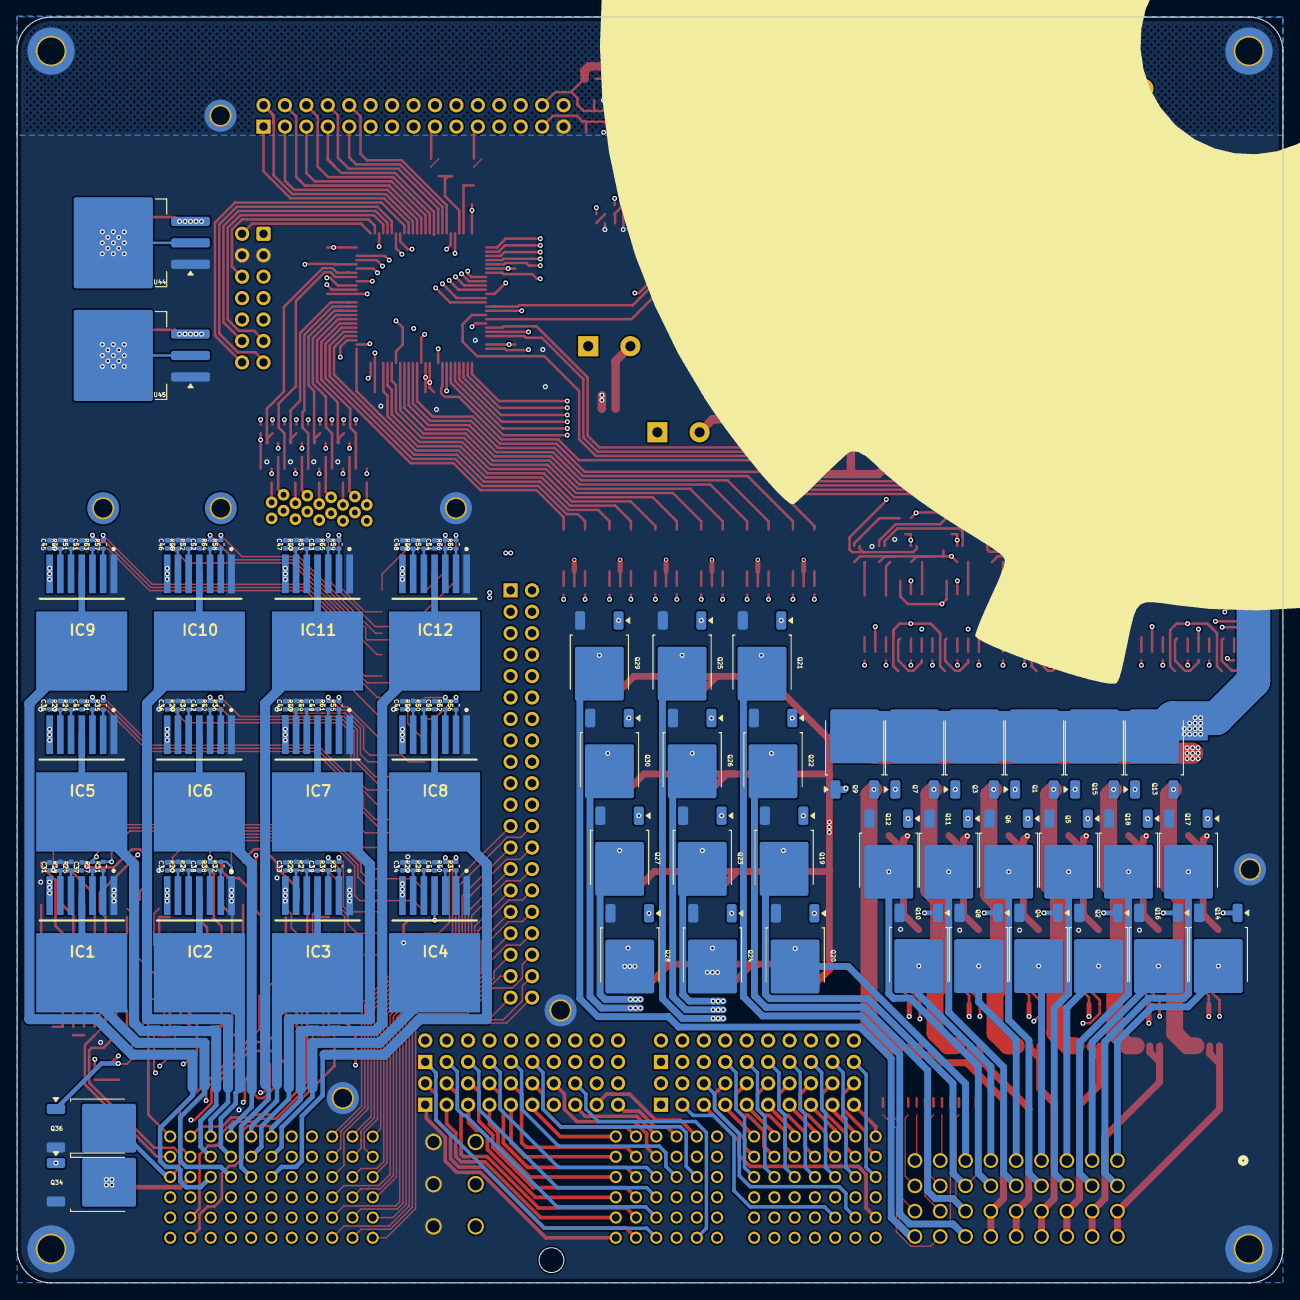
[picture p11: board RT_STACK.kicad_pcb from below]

Board: 6 copper layers, 150.0 x 150.0 mm, 483 parts (122 on the bottom side), 498 nets.

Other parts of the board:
C92, C93: 15pF; C_0402_1005Metric
C94, C95, C96, C97, C98, C99, C100, C101: 100nf; C_0402_1005Metric
C118, C119, C120, C121: 10uF; CP_Elec_5x4.5
C122, C123: 47p; C_0402_1005Metric
C124: 100n; C_0402_1005Metric
D51, D52, D53, D54, D55, D56: LED; LED_0402_1005Metric
JP4: Jumper_2_Open; SolderJumper-2_P1.3mm_Open_RoundedPad1.0x1.5mm
R141, R142, R143: 5k; R_0402_1005Metric
R144, R146: 1k; R_0402_1005Metric
R145: 25k; R_0402_1005Metric
R147, R166, R167: 200; R_0402_1005Metric
R168: 60; R_0402_1005Metric
U41: STM32G474VETx; LQFP-100_14x14mm_P0.5mm
U44: LM1084-5.0; TO-263-3_TabPin2
U45: LM1084-3.3; TO-263-3_TabPin2
U55: TJA1051T-3; SOIC-8_3.9x4.9mm_P1.27mm
Y1: Crystal_GND24; Crystal_SMD_2016-4Pin_2.0x1.6mm

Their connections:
+3.3V: C94.1, C95.1, C96.1, C97.1, C98.1, C99.1, C100.1, C101.1, C121.1, R147.2, U41.6 (VBAT), U41.24 (VDD), U41.36 (VREF+), U41.37 (VDDA), U41.49 (VDD), U41.64 (VDD), U41.75 (VDD), U41.100 (VDD), U45.2 (VO), U55.5 (VIO); also elsewhere on the board
+5V: C119.1, C124.2, R141.2, U44.2 (VO), U55.3 (VCC); also elsewhere on the board
+BATT: C118.1, C120.1, R143.2, U44.3 (VI), U45.3 (VI); also elsewhere on the board
/MCU/CAN_RX: U41.73 (PA12), U55.4 (RXD)
/MCU/CAN_TX: U41.72 (PA11), U55.1 (TXD)
/MCU/VBATT_ADC: D52.2 (A), R143.1, R144.2, U41.34 (PB2)
/MCU/VBUS_ADC: D53.2 (A), R145.1, R146.2, U41.18 (PC3)
BOOST12: U41.31 (PC5); also elsewhere on the board
BOOST34: U41.30 (PC4); also elsewhere on the board
BOOST56: U41.29 (PA7); also elsewhere on the board
BOOST78: U41.28 (PA6); also elsewhere on the board
BOOST910: U41.26 (PA4); also elsewhere on the board
BOOST1112: U41.27 (PA5); also elsewhere on the board
CAN1_H: C122.1, JP4.2 (B), U55.7 (CANH); also elsewhere on the board
CAN1_L: C123.2, R168.1, U55.6 (CANL); also elsewhere on the board
COMP_IN1: U41.21 (PA1); also elsewhere on the board
COMP_IN2: U41.25 (PA3); also elsewhere on the board
COMP_IN3: U41.16 (PC1); also elsewhere on the board
COMP_IN4: U41.32 (PB0); also elsewhere on the board
COMP_IN5: U41.52 (PB13); also elsewhere on the board
COMP_IN6: U41.50 (PB11); also elsewhere on the board
COMP_IN7: U41.53 (PB14); also elsewhere on the board
COMP_OUT1: U41.20 (PA0); also elsewhere on the board
COMP_OUT2: U41.22 (PA2); also elsewhere on the board
COMP_OUT3: U41.17 (PC2); also elsewhere on the board
COMP_OUT4: U41.33 (PB1); also elsewhere on the board
COMP_OUT5: U41.66 (PC7); also elsewhere on the board
COMP_OUT6: U41.65 (PC6); also elsewhere on the board
COMP_OUT7: U41.67 (PC8); also elsewhere on the board
DCDC_TIM1_1: U41.15 (PC0); also elsewhere on the board
DCDC_TIM1_3: U41.44 (PE13); also elsewhere on the board
GND: C92.2, C93.2, C94.2, C95.2, C96.2, C97.2, C98.2, C99.2, C100.2, C101.2, C118.2, C119.2, C120.2, C121.2, C122.2, C123.1, C124.1, D51.1 (K), D52.1 (K), D53.1 (K), D54.1 (K), D55.1 (K), D56.1 (K), R142.1, R144.1, R146.1, U41.23 (VSS), U41.35 (VSSA), U41.48 (VSS), U41.63 (VSS), U41.74 (VSS), U41.99 (VSS), U44.1 (GND), U45.1 (GND), U55.2 (GND), U55.8 (S), Y1.2, Y1.4; also elsewhere on the board
IGN1: U41.40 (PE9); also elsewhere on the board
IGN2: U41.39 (PE8); also elsewhere on the board
IGN3: U41.42 (PE11); also elsewhere on the board
IGN4: U41.41 (PE10); also elsewhere on the board
IGN5: U41.45 (PE14); also elsewhere on the board
IGN6: U41.43 (PE12); also elsewhere on the board
IGN7: U41.47 (PB10); also elsewhere on the board
IGN8: U41.46 (PE15); also elsewhere on the board
IGN9: U41.54 (PB15); also elsewhere on the board
IGN10: U41.51 (PB12); also elsewhere on the board
IGN11: U41.56 (PD9); also elsewhere on the board
IGN12: U41.55 (PD8); also elsewhere on the board
INJ12_sel: U41.1 (PE2); also elsewhere on the board
INJ34_sel: U41.2 (PE3); also elsewhere on the board
INJ56_sel: U41.3 (PE4); also elsewhere on the board
INJ78_sel: U41.4 (PE5); also elsewhere on the board
INJ910_sel: U41.7 (PC13); also elsewhere on the board
INJ1112_sel: U41.5 (PE6); also elsewhere on the board
unnamed: D51.2 (A), R141.1, R142.2
unnamed: D54.2 (A), R147.1
unnamed: D55.2 (A), R166.1
unnamed: D56.2 (A), R167.1
unnamed: JP4.1 (A), R168.2
unnamed: C92.1, U41.97 (PE0), Y1.1
unnamed: C93.1, U41.98 (PE1), Y1.3
PA9: U41.70 (PA9); also elsewhere on the board
PA15: U41.78 (PA15); also elsewhere on the board
PB3: U41.90 (PB3); also elsewhere on the board
PB4: U41.91 (PB4); also elsewhere on the board
PB5: U41.92 (PB5); also elsewhere on the board
PB6: U41.93 (PB6); also elsewhere on the board
PB7: U41.94 (PB7); also elsewhere on the board
PB8: U41.95 (PB8); also elsewhere on the board
PB9: U41.96 (PB9); also elsewhere on the board
PC14: U41.8 (PC14); also elsewhere on the board
PC15: U41.9 (PC15); also elsewhere on the board
PD0: U41.82 (PD0); also elsewhere on the board
PD1: U41.83 (PD1); also elsewhere on the board
PD3: U41.85 (PD3); also elsewhere on the board
PD4: U41.86 (PD4); also elsewhere on the board
PD5: U41.87 (PD5); also elsewhere on the board
PD6: U41.88 (PD6); also elsewhere on the board
PD7: U41.89 (PD7); also elsewhere on the board
PE7: U41.38 (PE7); also elsewhere on the board
PF0: U41.12 (PF0); also elsewhere on the board
PF1: U41.13 (PF1); also elsewhere on the board
PF2: R166.2, U41.19 (PF2); also elsewhere on the board
PF9: U41.10 (PF9); also elsewhere on the board
PF10: R167.2, U41.11 (PF10); also elsewhere on the board
PG10: U41.14 (PG10); also elsewhere on the board
S4_RX: U41.80 (PC11); also elsewhere on the board
S4_TX: U41.79 (PC10); also elsewhere on the board
S5_RX: U41.84 (PD2); also elsewhere on the board
S5_TX: U41.81 (PC12); also elsewhere on the board
SWCLK: U41.77 (PA14); also elsewhere on the board
SWDIO: U41.76 (PA13); also elsewhere on the board
TMG_OUT1: U41.57 (PD10); also elsewhere on the board
TMG_OUT2: U41.59 (PD12); also elsewhere on the board
TMG_OUT3: U41.68 (PC9); also elsewhere on the board
TMG_OUT4: U41.61 (PD14); also elsewhere on the board
TMG_OUT5: U41.71 (PA10); also elsewhere on the board
TMG_OUT6: U41.58 (PD11); also elsewhere on the board
TMG_OUT7: U41.60 (PD13); also elsewhere on the board
TMG_OUT8: U41.62 (PD15); also elsewhere on the board
TMG_OUT9: U41.69 (PA8); also elsewhere on the board
VBUS: R145.2; also elsewhere on the board

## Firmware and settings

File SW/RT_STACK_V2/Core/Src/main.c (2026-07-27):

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
/* Includes ------------------------------------------------------------------*/
#include "main.h"

/* USER CODE BEGIN Includes */
#include <stdio.h>
#include <stdbool.h>
#include "board_config.h"
#include "board_safety_stm32.h"
#include "diagnostics_can.h"
#include "dcdc_platform_stm32.h"
#include "engine_control.h"
#include "engine_watchdog_stm32.h"
#include "trigger_capture_stm32.h"
/* USER CODE END Includes */

/* USER CODE BEGIN PTD */
/* Injection/ignition types live in injection.c / spark.c; the hardware maps
 * live in engine_config.h. */
/* USER CODE END PTD */

/* USER CODE BEGIN PD */
/* TMG_CH_COUNT is defined in trigger_decoder.h (sizes the tmg_* arrays).
 * Engine calibration (cylinders, channels, thresholds) is in engine_config.h. */

/* Measured analog reference voltage, in mV (ADC conversions) */
#define VDDA_MV         3200U

enum
{
  ADC1_IDX_COMP1 = 0U,
  ADC1_IDX_COMP2 = 1U,
  ADC1_IDX_COMP3 = 2U,
  ADC1_IDX_VBUS  = 3U,
  ADC1_IDX_COMP6 = 4U,
  ADC1_IDX_TEMP  = 5U,
  ADC1_IDX_VREF  = 6U,
  ADC1_IDX_COMP4 = 7U,
  ADC3_IDX_COMP5 = 0U,
};
/* USER CODE END PD */

ADC_HandleTypeDef hadc1;
ADC_HandleTypeDef hadc2;
ADC_HandleTypeDef hadc3;
DMA_HandleTypeDef hdma_adc1;
DMA_HandleTypeDef hdma_adc3;

COMP_HandleTypeDef hcomp1;
COMP_HandleTypeDef hcomp2;
COMP_HandleTypeDef hcomp3;
COMP_HandleTypeDef hcomp4;
COMP_HandleTypeDef hcomp5;
COMP_HandleTypeDef hcomp6;
COMP_HandleTypeDef hcomp7;

DAC_HandleTypeDef hdac1;
DAC_HandleTypeDef hdac2;
DAC_HandleTypeDef hdac3;
DAC_HandleTypeDef hdac4;

FDCAN_HandleTypeDef hfdcan1;

TIM_HandleTypeDef htim1;

UART_HandleTypeDef huart4;
UART_HandleTypeDef huart5;

/* USER CODE BEGIN PV */
volatile uint16_t ADC_VAL_adc1[8];
volatile uint16_t ADC_VAL_adc3[1];
static uint16_t adc2_vbatt_raw;

typedef struct
{
  uint16_t comp1_raw;
  uint16_t comp2_raw;
  uint16_t comp3_raw;
  uint16_t comp4_raw;
  uint16_t comp5_raw;
  uint16_t comp6_raw;
  uint16_t vbus_raw;
  uint16_t temp_raw;
  uint16_t vref_raw;
  uint16_t vbat_raw;
} adc_snapshot_t;
/* USER CODE END PV */

void SystemClock_Config(void);
static void MX_GPIO_Init(void);
static void MX_DMA_Init(void);
static void MX_COMP2_Init(void);
static void MX_COMP3_Init(void);
static void MX_COMP4_Init(void);
static void MX_COMP5_Init(void);
static void MX_COMP6_Init(void);
static void MX_COMP7_Init(void);
static void MX_DAC1_Init(void);
static void MX_DAC2_Init(void);
static void MX_DAC3_Init(void);
static void MX_DAC4_Init(void);
static void MX_TIM1_Init(void);
static void MX_UART4_Init(void);
static void MX_UART5_Init(void);
static void MX_ADC1_Init(void);
static void MX_FDCAN1_Init(void);
static void MX_COMP1_Init(void);
static void MX_ADC3_Init(void);
static void MX_ADC2_Init(void);
/* USER CODE BEGIN 0 */
/**
 * @brief Force boot from flash via option bytes (one-shot).
 *
 * The board has no pull-down on BOOT0/PB8: if the pin samples high at reset
 * the ST bootloader runs and the application is not executed. This sets
 * nSWBOOT0=0 (boot ignores the pin) and nBOOT0=1 (boot from flash). If the
 * option bytes are already correct it does nothing; otherwise it programs them
 * and HAL_FLASH_OB_Launch() triggers a reset (does not return).
 */
static void boot_from_flash_ob_init(void)
{
  if (((FLASH->OPTR & FLASH_OPTR_nSWBOOT0) == 0U) &&
      ((FLASH->OPTR & FLASH_OPTR_nBOOT0) != 0U))
  {
    return;   /* already configured: always boots from flash */
  }

  FLASH_OBProgramInitTypeDef ob = {0};

  HAL_FLASH_Unlock();
  HAL_FLASH_OB_Unlock();

  ob.OptionType = OPTIONBYTE_USER;
  ob.USERType   = OB_USER_nSWBOOT0 | OB_USER_nBOOT0;
  ob.USERConfig = OB_BOOT0_FROM_OB | OB_nBOOT0_SET;

  if (HAL_FLASHEx_OBProgram(&ob) == HAL_OK)
  {
    HAL_FLASH_OB_Launch();   /* apply and reset the MCU: does not return */
  }

  /* Programming failed: re-lock the flash and signal */
  HAL_FLASH_OB_Lock();
  HAL_FLASH_Lock();
  Error_Handler();
}

static void injector_comparator_hysteresis_init(void)
{
  COMP_HandleTypeDef *const comparators[] = {
    &hcomp1, &hcomp2, &hcomp3, &hcomp4, &hcomp5, &hcomp6,
  };

  for (uint32_t i = 0U; i < (sizeof(comparators) / sizeof(comparators[0])); ++i)
  {
    comparators[i]->Init.Hysteresis = BOARD_INJECTOR_COMPARATOR_HYSTERESIS;
    MODIFY_REG(comparators[i]->Instance->CSR, COMP_CSR_HYST,
               BOARD_INJECTOR_COMPARATOR_HYSTERESIS);
  }
}

static adc_snapshot_t adc_snapshot_read(void)
{
  if (__HAL_ADC_GET_FLAG(&hadc2, ADC_FLAG_EOC) != 0U)
  {
    adc2_vbatt_raw = (uint16_t)HAL_ADC_GetValue(&hadc2);
  }

  adc_snapshot_t adc = {
    .comp1_raw = ADC_VAL_adc1[ADC1_IDX_COMP1],
    .comp2_raw = ADC_VAL_adc1[ADC1_IDX_COMP2],
    .comp3_raw = ADC_VAL_adc1[ADC1_IDX_COMP3],
    .comp4_raw = ADC_VAL_adc1[ADC1_IDX_COMP4],
    .comp5_raw = ADC_VAL_adc3[ADC3_IDX_COMP5],
    .comp6_raw = ADC_VAL_adc1[ADC1_IDX_COMP6],
    .vbus_raw  = ADC_VAL_adc1[ADC1_IDX_VBUS],
    .temp_raw  = ADC_VAL_adc1[ADC1_IDX_TEMP],
    .vref_raw  = ADC_VAL_adc1[ADC1_IDX_VREF],
    .vbat_raw  = adc2_vbatt_raw,
  };

  return adc;
}

/* USER CODE END 0 */

/**
  * @brief  The application entry point.
  * @retval int
  */
int main(void)
{

  /* USER CODE BEGIN 1 */
  /* Force the vector table into flash. With VTOR=0 (G4 default) the vectors
   * depend on how BOOT0 (PB8) is sampled at reset: if it is not pulled low,
   * exceptions land in the ST bootloader's table and SysTick/EXTI never reach
   * the application handlers. */
  SCB->VTOR = FLASH_BASE;
  __DSB();
  /* The PCB has no external actuator pull-downs/global enable.  Reduce the
   * high-impedance boot window before HAL, clocks, or option-byte work. */
  board_force_actuator_pins_low_early();
  /* USER CODE END 1 */

  /* MCU Configuration--------------------------------------------------------*/

  /* Reset of all peripherals, Initializes the Flash interface and the Systick. */
  HAL_Init();

  /* USER CODE BEGIN Init */
  boot_from_flash_ob_init();
  /* USER CODE END Init */

  /* Configure the system clock */
  SystemClock_Config();

  /* USER CODE BEGIN SysInit */
  HAL_RCC_EnableCSS();
  /* USER CODE END SysInit */

  /* Initialize all configured peripherals */
  MX_GPIO_Init();
  MX_DMA_Init();
  MX_COMP2_Init();
  MX_COMP3_Init();
  MX_COMP4_Init();
  MX_COMP5_Init();
  MX_COMP6_Init();
  MX_COMP7_Init();
  MX_DAC1_Init();
  MX_DAC2_Init();
  MX_DAC3_Init();
  MX_DAC4_Init();
  MX_TIM1_Init();
  MX_UART4_Init();
  MX_UART5_Init();
  MX_ADC1_Init();
  MX_FDCAN1_Init();
  MX_COMP1_Init();
  MX_ADC3_Init();
  MX_ADC2_Init();
  /* USER CODE BEGIN 2 */
  /* CubeMX currently emits COMP_HYSTERESIS_NONE. Apply the board-level value
   * from a preserved user block before injection can start a comparator. */
  injector_comparator_hysteresis_init();

  const dcdc_platform_stm32_config_t dcdc_platform_config = {
    .pwm_timer = &htim1,
    .vbus_adc = &hadc1,
    .adc_dma_values = ADC_VAL_adc1,
    .adc_dma_value_count = 8U,
    .vbus_dma_index = ADC1_IDX_VBUS,
    .vref_dma_index = ADC1_IDX_VREF,
    .fallback_vdda_mv = VDDA_MV,
  };
  if (!dcdc_platform_stm32_init(&dcdc_platform_config, HAL_GetTick()))
  {
    Error_Handler();
  }

  HAL_NVIC_DisableIRQ(DMA1_Channel1_IRQn);
  HAL_NVIC_DisableIRQ(DMA1_Channel2_IRQn);
  /* ADC DMA priority at the minimum (the IRQs stay disabled anyway) */
  HAL_NVIC_SetPriority(DMA1_Channel1_IRQn, 15, 0);
  HAL_NVIC_SetPriority(DMA1_Channel2_IRQn, 15, 0);

  if (HAL_ADCEx_Calibration_Start(&hadc1, ADC_SINGLE_ENDED) != HAL_OK)
  {
    Error_Handler();
  }

  if (HAL_ADCEx_Calibration_Start(&hadc3, ADC_SINGLE_ENDED) != HAL_OK)
  {
    Error_Handler();
  }

  if (HAL_ADCEx_Calibration_Start(&hadc2, ADC_SINGLE_ENDED) != HAL_OK)
  {
    Error_Handler();
  }

  if (!dcdc_platform_stm32_configure_analog_watchdog())
  {
    Error_Handler();
  }

  if (HAL_ADC_Start_DMA(&hadc1, (uint32_t *)ADC_VAL_adc1, 8U) != HAL_OK)
  {
    Error_Handler();
  }
  __HAL_DMA_DISABLE_IT(&hdma_adc1, DMA_IT_HT | DMA_IT_TC);

  if (HAL_ADC_Start_DMA(&hadc3, (uint32_t *)ADC_VAL_adc3, 1U) != HAL_OK)
  {
    Error_Handler();
  }
  __HAL_DMA_DISABLE_IT(&hdma_adc3, DMA_IT_HT | DMA_IT_TC);

  if (HAL_ADC_Start(&hadc2) != HAL_OK)
  {
    Error_Handler();
  }

  if (!dcdc_platform_stm32_start())
  {
    Error_Handler();
  }

#if (BOARD_FDCAN1_TRANSCEIVER_WIRING_FIXED != 0U)
  if ((diagnostics_can_init(&hfdcan1) != HAL_OK) ||
      (HAL_FDCAN_Start(&hfdcan1) != HAL_OK))
  {
    Error_Handler();
  }
#endif

  /* Initialize the consumer before enabling any trigger producer.  TIM2 is a
   * common clock for captured/EXTI edges and actuator hard deadlines. */
  const trigger_decoder_config_t *trigger_config =
      trigger_decoder_default_config();
  (void)engine_control_init(trigger_config, trigger_capture_timestamp_hz());
  /* Start supervision before trigger IRQs. A noisy/stuck input must not be
   * able to starve foreground activation of the watchdog. */
  if (!engine_watchdog_stm32_start())
  {
    engine_control_emergency_fault_isr(ENGINE_FAULT_PLATFORM);
    Error_Handler();
  }
  if (!trigger_capture_stm32_init(trigger_config))
  {
    engine_control_emergency_fault_isr(ENGINE_FAULT_PLATFORM);
    Error_Handler();
  }

  /* USER CODE END 2 */

  /* Infinite loop */
  /* USER CODE BEGIN WHILE */
  while (1)
  {
    const uint32_t now_ms = HAL_GetTick();
    engine_control_state_t engine;
    engine_control_service();
    engine_control_get_state(&engine);

    dcdc_platform_stm32_service(now_ms);

    adc_snapshot_t adc = adc_snapshot_read();
    uint32_t vdda_mv = (adc.vref_raw != 0U) ?
        __HAL_ADC_CALC_VREFANALOG_VOLTAGE(adc.vref_raw, ADC_RESOLUTION_12B) :
        VDDA_MV;

#if (BOARD_FDCAN1_TRANSCEIVER_WIRING_FIXED != 0U)
    int32_t temp_celsius = __HAL_ADC_CALC_TEMPERATURE(
        vdda_mv, adc.temp_raw, ADC_RESOLUTION_12B);

    diagnostics_sensor_snapshot_t sensors = {
      .mcu_temperature_c = temp_celsius,
      .external_vbatt_raw = adc.vbat_raw,
      .vbus_raw = adc.vbus_raw,
      .vdda_mv = (uint16_t)vdda_mv,
    };
    diagnostics_can_service(now_ms, &engine, &sensors);
#else
    /* ADC values remain visible to a debugger while the unsafe CAN route is
     * disabled. adc_snapshot_read() above also clears ADC2 EOC/overrun. */
    (void)adc;
    (void)vdda_mv;
#endif

    /* Refresh only after the complete foreground control/diagnostics pass.
     * A deadlock or unbounded service therefore causes a hardware reset. */
    engine_watchdog_stm32_refresh();

  }
    /* USER CODE END WHILE */

}

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
/* USER CODE BEGIN 4 */
int _write(int file, char *ptr, int len) {
    (void)file;
    for (int i = 0; i < len; i++) {
        ITM_SendChar((*ptr++));
    }
    return len;
}

/* USER CODE END 4 */
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


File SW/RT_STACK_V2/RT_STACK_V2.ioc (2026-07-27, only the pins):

Mcu.UserName=STM32G474VETx
PA0.Signal=COMP1_OUT
PA1.Signal=SharedAnalog_PA1
PA10.GPIO_Label=TMG_OUT5
PA10.Signal=GPIO_Input
PA11.Signal=FDCAN1_RX
PA12.Signal=FDCAN1_TX
PA2.Signal=COMP2_OUT
PA3.Signal=SharedAnalog_PA3
PA4.GPIO_Label=BOOST910
PA4.Signal=GPIO_Output
PA5.GPIO_Label=BOOST1112
PA5.Signal=GPIO_Output
PA6.GPIO_Label=BOOST78
PA6.Signal=GPIO_Output
PA7.GPIO_Label=BOOST56
PA7.Signal=GPIO_Output
PA8.GPIO_Label=TMG_OUT9
PA8.Signal=GPIO_Input
PB0.Signal=SharedAnalog_PB0
PB1.Signal=COMP4_OUT
PB10.GPIO_Label=IGN7
PB10.Signal=GPIO_Output
PB11.Signal=SharedAnalog_PB11
PB12.GPIO_Label=IGN10
PB12.Signal=GPIO_Output
PB13.Signal=SharedAnalog_PB13
PB14.Signal=COMP7_INP
PB15.GPIO_Label=IGN9
PB15.Signal=GPIO_Output
PB2.GPIO_Label=VBATT
PB2.Signal=ADC2_IN12
PC0.Signal=S_TIM1_CH1
PC1.Signal=SharedAnalog_PC1
PC10.Signal=UART4_TX
PC11.Signal=UART4_RX
PC12.Signal=UART5_TX
PC13.GPIO_Label=SEL910
PC13.Signal=GPIO_Output
PC2.Signal=COMP3_OUT
PC3.GPIO_Label=VBUS
PC3.Signal=ADC1_IN9
PC4.GPIO_Label=BOOST34
PC4.Signal=GPIO_Output
PC5.GPIO_Label=BOOST12
PC5.Signal=GPIO_Output
PC6.Signal=COMP6_OUT
PC7.Signal=COMP5_OUT
PC8.Signal=COMP7_OUT
PC9.GPIO_Label=TMG_OUT3
PC9.Signal=GPIO_Input
PD10.GPIO_Label=TMG_OUT1
PD10.Signal=GPIO_Input
PD11.GPIO_Label=TMG_OUT6
PD11.Signal=GPIO_Input
PD12.GPIO_Label=TMG_OUT2
PD12.Signal=GPIO_Input
PD13.GPIO_Label=TMG_OUT7
PD13.Signal=GPIO_Input
PD14.GPIO_Label=TMG_OUT4
PD14.Signal=GPIO_Input
PD15.GPIO_Label=TMG_OUT8
PD15.Signal=GPIO_Input
PD2.Signal=UART5_RX
PD8.GPIO_Label=IGN12
PD8.Signal=GPIO_Output
PD9.GPIO_Label=IGN11
PD9.Signal=GPIO_Output
PE10.GPIO_Label=IGN4
PE10.Signal=GPIO_Output
PE11.GPIO_Label=IGN3
PE11.Signal=GPIO_Output
PE12.GPIO_Label=IGN6
PE12.Signal=GPIO_Output
PE13.Signal=S_TIM1_CH3
PE14.GPIO_Label=IGN5
PE14.Signal=GPIO_Output
PE15.GPIO_Label=IGN8
PE15.Signal=GPIO_Output
PE2.GPIO_Label=SEL12
PE2.Signal=GPIO_Output
PE3.GPIO_Label=SEL34
PE3.Signal=GPIO_Output
PE4.GPIO_Label=SEL56
PE4.Signal=GPIO_Output
PE5.GPIO_Label=SEL78
PE5.Signal=GPIO_Output
PE6.GPIO_Label=SEL1112
PE6.Signal=GPIO_Output
PE8.GPIO_Label=IGN2
PE8.Signal=GPIO_Output
PE9.GPIO_Label=IGN1
PE9.Signal=GPIO_Output
PF0-OSC_IN.Signal=RCC_OSC_IN
PF1-OSC_OUT.Signal=RCC_OSC_OUT
PF10.GPIO_Label=LED2
PF10.Signal=GPIO_Output
PF2.GPIO_Label=LED1
PF2.Signal=GPIO_Output

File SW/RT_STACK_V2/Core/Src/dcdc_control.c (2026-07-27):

/**
 ******************************************************************************
 * @file    dcdc_control.c
 * @brief   Fixed-rate VBUS controller with soft start and latched shutdowns.
 ******************************************************************************
 */
#include "dcdc_control.h"

#include <math.h>
#include <stddef.h>

#include "dcdc_config.h"

#define PERMILLE_TO_DUTY 0.001f
#define MV_TO_VOLTS       0.001f

typedef struct
{
  dcdc_control_config_t config;
  dcdc_pwm_driver_t driver;
  volatile dcdc_mode_t mode;
  volatile uint32_t faults;
  volatile bool initialized;
  volatile bool enable_requested;
  volatile bool pwm_running;
  volatile uint32_t foreground_heartbeat_ms;
  volatile uint32_t latest_sample_ms;
  volatile bool sample_seen;
  volatile bool latest_sample_valid;

  uint32_t latest_vbus_mv;
  uint32_t requested_target_mv;
  float ramped_target_mv;
  float filtered_vbus_mv;
  float previous_filtered_vbus_mv;
  float filtered_derivative_volts_per_second;
  float integral_duty;
  uint16_t confirmed_sample_count;
  uint16_t applied_duty_permille;
  uint32_t enable_requested_at_ms;
  uint32_t last_control_ms;
} dcdc_controller_t;

static dcdc_controller_t controller;

static const dcdc_control_config_t default_config = {
  .output_calibration_valid = (DCDC_OUTPUT_PERMISSION != 0U),
  .vbus_plausible_min_mv = DCDC_VBUS_PLAUSIBLE_MIN_MV,
  .vbus_plausible_max_mv = DCDC_VBUS_PLAUSIBLE_MAX_MV,
  .target_min_mv = DCDC_VBUS_TARGET_MIN_MV,
  .target_default_mv = DCDC_VBUS_TARGET_DEFAULT_MV,
  .target_max_mv = DCDC_VBUS_TARGET_MAX_MV,
  .overvoltage_reset_mv = DCDC_VBUS_OVERVOLTAGE_RESET_MV,
  .overvoltage_trip_mv = DCDC_VBUS_OVERVOLTAGE_TRIP_MV,
  .control_period_ms = DCDC_CONTROL_PERIOD_MS,
  .control_deadline_ms = DCDC_CONTROL_DEADLINE_MS,
  .sample_timeout_ms = DCDC_VBUS_SAMPLE_TIMEOUT_MS,
  .startup_valid_sample_count = DCDC_STARTUP_VALID_SAMPLE_COUNT,
  .soft_start_mv_per_second = DCDC_SOFT_START_MV_PER_SECOND,
  .minimum_active_duty_permille = DCDC_MINIMUM_ACTIVE_DUTY_PERMILLE,
  .maximum_duty_permille = DCDC_MAXIMUM_DUTY_PERMILLE,
  .duty_rise_per_control_permille =
      DCDC_DUTY_RISE_PER_CONTROL_PERMILLE,
  .duty_fall_per_control_permille =
      DCDC_DUTY_FALL_PER_CONTROL_PERMILLE,
  .kp_duty_per_volt = DCDC_PID_KP_DUTY_PER_VOLT,
  .ki_duty_per_volt_second = DCDC_PID_KI_DUTY_PER_VOLT_SECOND,
  .kd_duty_second_per_volt = DCDC_PID_KD_DUTY_SECOND_PER_VOLT,
  .anti_windup_per_second = DCDC_PID_ANTI_WINDUP_PER_SECOND,
  .measurement_filter_time_constant_ms =
      DCDC_VBUS_FILTER_TIME_CONSTANT_MS,
  .derivative_filter_time_constant_ms =
      DCDC_DERIVATIVE_FILTER_TIME_CONSTANT_MS,
};

static float clamp_float(float value, float low, float high)
{
  if (value < low)
  {
    return low;
  }
  if (value > high)
  {
    return high;
  }
  return value;
}

static uint16_t move_duty_toward(uint16_t current, uint16_t requested)
{
  if (requested > current)
  {
    uint32_t next = (uint32_t)current +
                    controller.config.duty_rise_per_control_permille;
    return (uint16_t)((next < requested) ? next : requested);
  }
  if (requested < current)
  {
    uint16_t step = controller.config.duty_fall_per_control_permille;
    if ((uint32_t)requested + step < current)
    {
      return (uint16_t)(current - step);
    }
    return requested;
  }
  return current;
}

static bool driver_is_complete(const dcdc_pwm_driver_t *driver)
{
  return (driver != NULL) && (driver->start != NULL) &&
         (driver->set_duty_permille != NULL) && (driver->stop != NULL) &&
         (driver->is_running != NULL) &&
         (driver->critical_enter != NULL) &&
         (driver->critical_exit != NULL);
}

static bool full_config_is_valid(const dcdc_control_config_t *config)
{
  if ((config == NULL) || (config->control_period_ms == 0U) ||
      (config->control_deadline_ms < (2U * config->control_period_ms)) ||
      (config->sample_timeout_ms < config->control_period_ms) ||
      (config->startup_valid_sample_count == 0U))
  {
    return false;
  }

  if (!config->output_calibration_valid)
  {
    return true;
  }

  if ((config->vbus_plausible_min_mv >= config->target_min_mv) ||
      (config->target_min_mv > config->target_default_mv) ||
      (config->target_default_mv > config->target_max_mv) ||
      (config->target_max_mv > config->overvoltage_reset_mv) ||
      (config->overvoltage_reset_mv >= config->overvoltage_trip_mv) ||
      (config->overvoltage_trip_mv > config->vbus_plausible_max_mv) ||
      (config->soft_start_mv_per_second == 0U) ||
      (config->minimum_active_duty_permille == 0U) ||
      (config->minimum_active_duty_permille >
       config->maximum_duty_permille) ||
      (config->maximum_duty_permille >= 1000U) ||
      (config->duty_rise_per_control_permille == 0U) ||
      (config->duty_fall_per_control_permille == 0U) ||
      !isfinite(config->kp_duty_per_volt) ||
      !isfinite(config->ki_duty_per_volt_second) ||
      !isfinite(config->kd_duty_second_per_volt) ||
      !isfinite(config->anti_windup_per_second) ||
      (config->kp_duty_per_volt < 0.0f) ||
      (config->ki_duty_per_volt_second < 0.0f) ||
      (config->kd_duty_second_per_volt < 0.0f) ||
      (config->anti_windup_per_second <= 0.0f) ||
      ((config->kp_duty_per_volt == 0.0f) &&
       (config->ki_duty_per_volt_second == 0.0f)))
  {
    return false;
  }
  return true;
}

static void reset_pid(void)
{
  controller.ramped_target_mv = 0.0f;
  controller.filtered_vbus_mv = 0.0f;
  controller.previous_filtered_vbus_mv = 0.0f;
  controller.filtered_derivative_volts_per_second = 0.0f;
  controller.integral_duty = 0.0f;
  controller.confirmed_sample_count = 0U;
  controller.applied_duty_permille = 0U;
}

static void stop_pwm(void)
{
  if (controller.initialized)
  {
    controller.driver.stop(controller.driver.context);
  }
  controller.pwm_running = false;
  controller.applied_duty_permille = 0U;
}

static void latch_fault(uint32_t fault)
{
  uint32_t critical_token =
      controller.driver.critical_enter(controller.driver.context);

  stop_pwm();
  controller.faults |= fault;
  controller.enable_requested = false;
  controller.mode = DCDC_MODE_FAULT;
  controller.driver.critical_exit(controller.driver.context, critical_token);
}

static bool sample_is_plausible(const dcdc_vbus_sample_t *sample)
{
  return sample->valid &&
         (sample->vbus_mv >= controller.config.vbus_plausible_min_mv) &&
         (sample->vbus_mv <= controller.config.vbus_plausible_max_mv);
}

const dcdc_control_config_t *dcdc_control_default_config(void)
{
  return &default_config;
}
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

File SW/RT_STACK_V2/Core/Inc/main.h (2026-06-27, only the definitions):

#define SEL12_Pin GPIO_PIN_2
#define SEL12_GPIO_Port GPIOE
#define SEL34_Pin GPIO_PIN_3
#define SEL34_GPIO_Port GPIOE
#define SEL56_Pin GPIO_PIN_4
#define SEL56_GPIO_Port GPIOE
#define SEL78_Pin GPIO_PIN_5
#define SEL78_GPIO_Port GPIOE
#define SEL1112_Pin GPIO_PIN_6
#define SEL1112_GPIO_Port GPIOE
#define SEL910_Pin GPIO_PIN_13
#define SEL910_GPIO_Port GPIOC
#define LED2_Pin GPIO_PIN_10
#define LED2_GPIO_Port GPIOF
#define VBUS_Pin GPIO_PIN_3
#define VBUS_GPIO_Port GPIOC
#define LED1_Pin GPIO_PIN_2
#define LED1_GPIO_Port GPIOF
#define BOOST910_Pin GPIO_PIN_4
#define BOOST910_GPIO_Port GPIOA
#define BOOST1112_Pin GPIO_PIN_5
#define BOOST1112_GPIO_Port GPIOA
#define BOOST78_Pin GPIO_PIN_6
#define BOOST78_GPIO_Port GPIOA
#define BOOST56_Pin GPIO_PIN_7
#define BOOST56_GPIO_Port GPIOA
#define BOOST34_Pin GPIO_PIN_4
#define BOOST34_GPIO_Port GPIOC
#define BOOST12_Pin GPIO_PIN_5
#define BOOST12_GPIO_Port GPIOC
#define VBATT_Pin GPIO_PIN_2
#define VBATT_GPIO_Port GPIOB
#define IGN2_Pin GPIO_PIN_8
#define IGN2_GPIO_Port GPIOE
#define IGN1_Pin GPIO_PIN_9
#define IGN1_GPIO_Port GPIOE
#define IGN4_Pin GPIO_PIN_10
#define IGN4_GPIO_Port GPIOE
#define IGN3_Pin GPIO_PIN_11
#define IGN3_GPIO_Port GPIOE
#define IGN6_Pin GPIO_PIN_12
#define IGN6_GPIO_Port GPIOE
#define IGN5_Pin GPIO_PIN_14
#define IGN5_GPIO_Port GPIOE
#define IGN8_Pin GPIO_PIN_15
#define IGN8_GPIO_Port GPIOE
#define IGN7_Pin GPIO_PIN_10
#define IGN7_GPIO_Port GPIOB
#define IGN10_Pin GPIO_PIN_12
#define IGN10_GPIO_Port GPIOB
#define IGN9_Pin GPIO_PIN_15
#define IGN9_GPIO_Port GPIOB
#define IGN12_Pin GPIO_PIN_8
#define IGN12_GPIO_Port GPIOD
#define IGN11_Pin GPIO_PIN_9
#define IGN11_GPIO_Port GPIOD
#define TMG_OUT1_Pin GPIO_PIN_10
#define TMG_OUT1_GPIO_Port GPIOD
#define TMG_OUT6_Pin GPIO_PIN_11
#define TMG_OUT6_GPIO_Port GPIOD
#define TMG_OUT2_Pin GPIO_PIN_12
#define TMG_OUT2_GPIO_Port GPIOD
#define TMG_OUT7_Pin GPIO_PIN_13
#define TMG_OUT7_GPIO_Port GPIOD
#define TMG_OUT4_Pin GPIO_PIN_14
#define TMG_OUT4_GPIO_Port GPIOD
#define TMG_OUT8_Pin GPIO_PIN_15
#define TMG_OUT8_GPIO_Port GPIOD
#define TMG_OUT3_Pin GPIO_PIN_9
#define TMG_OUT3_GPIO_Port GPIOC
#define TMG_OUT9_Pin GPIO_PIN_8
#define TMG_OUT9_GPIO_Port GPIOA
#define TMG_OUT5_Pin GPIO_PIN_10
#define TMG_OUT5_GPIO_Port GPIOA

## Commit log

2026-01-05 Alpha release
    First manifactured release
    [RT_STACK.kicad_pcb, RT_STACK.kicad_sch, conn.kicad_sch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]
2026-03-08 Ver2
    Second HW rev + SW update
    [RT_STACK.kicad_pcb, RT_STACK.kicad_sch, conn.kicad_sch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]
2026-03-09 v0.2 BOM
    [BOM.csv, BOM.xlsx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]
2026-04-05 FAB BOM/CPL
    add BOM/CPL JLCPCB reduced (only stm32/0402 components)
    [BOM.csv, BOM.xlsx, BOM_JLCSMT.xlsx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]
2026-06-27 Firmware
    Trigger wheels pattern detections
    Ignition scheduler
    Injection schedurer
    GDI support
    [dcdc.kicad_sch]
2026-07-27 conf engine core
    [STM32G474QE_PIN_ASSIGNMENT.csv, STM32G474QE_SERIAL_OUTPUT_ASSIGNMENT.csv]

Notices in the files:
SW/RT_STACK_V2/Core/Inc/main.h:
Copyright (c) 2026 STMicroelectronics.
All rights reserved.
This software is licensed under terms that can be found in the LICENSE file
